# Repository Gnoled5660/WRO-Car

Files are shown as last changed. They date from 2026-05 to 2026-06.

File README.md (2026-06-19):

# WRO-Car

Bildschirmfoto 2026-06-14 um 00 26 38

# Description

This car is meant to be used for a competition called WRO in the category Future-engineers. The goal is to have a car that drives autonomously around obstacles, in lapses ,as fast as possible, without having a collision with the wall or the obstacles. The obstacles may have different colors. Depending on the color, the car has to either drive around it from the left side or from the right side. 

All the 3D CAD models of the car, have been designed entirely from scratch. It is very much possible to design this with much cheaper electronics, but for this competition, we used some higher quality components, as we had a sponsor. 

The car is mainly seperated in two layers. One being the bottom layer, where almost all the non logical electrical components are, and one being the second layer, where all the logical electrical components are.

# Motivation

The main reason why I built this car is because it was required for a robotics competition. This is my first robotics competition, meaning I haven't got that much experience yet, but throughout this project, I have learned a lot about how these electrical components can work together, to be able to move itself. 

# Assembling and Wiring

Assembling it is quite straight forward. All the 3D CAD components have holes, where you can place a heated thread insert inside and screw the parts together. Every component is meant to be screwed or sticked together with glue.

Wiring is also fairly simple. Most of the components have either copper on the pad, so that you can solder the cable on to it or there are pin headers that you can simply connect to it. You just have to be careful with connecting it to the right pins or connecting V+ and Ground correctly. It is also important to use a wire with at least 18 or 20 AWG for the power supply, as it needs to be able to deliver a maximum of 5-6A. The rest of the signal pins can be connected with jumper cables.

The tires are lego tires, as well as the bar that holds the tire. However, it is completely possible to use 3D printed tires. Just be aware, that you might loose some grip.

# CAD Assembly
Starting with the main body, you need to insert heated threat inserts into all of the holes. All the holes are designed for M3 screws.

Bildschirmfoto 2026-06-18 um 15 10 32

Then you can glue the these parts of the steering gear onto the main body. You also have to insert a steel rod from the top to the bottom, to ensure that the component can rotate freely. The steel rods should have a diameter of 3mm.

Bildschirmfoto 2026-06-18 um 15 12 34

Bildschirmfoto 2026-06-18 um 15 15 00

Afterwards, you can add the rest of the components for the steering gear. All the parts that are red in this picture need a steel rod, to ensure flawless rotations.

Bildschirmfoto 2026-06-18 um 15 17 59

Now you can add the rest of the mounts.

Bildschirmfoto 2026-06-18 um 15 20 35

This part is a little bit tricky. It is important, that the servo mounts are added first and then comes the camera mount, because this why it is easier to reach the screws with a screwdriver. 

Bildschirmfoto 2026-06-18 um 15 21 45

The pillars for the second layer also need to be screwed. There is one screw hole on the bottom and two holes for threat inserts on the top. 

Bildschirmfoto 2026-06-18 um 15 23 50

After screwing every component to the mounts, it should look something like this.

Bildschirmfoto 2026-06-18 um 15 25 58

Now for the second layer, the screw sizes may vary from each other, as every component has different sizes of mounting holes. In the cad files you can look up how big the holes of the components are. They are usually 0.2mm bigger than the actual screw.

Bildschirmfoto 2026-06-18 um 15 27 07

If everything is built correctly, the result should look like this one.

Bildschirmfoto 2026-06-18 um 15 29 22

# Usage
The car is meant to be driven autonomously, but withthe raspberry pi5, it is also possible to program it to drive manually. The autonomous car can drive around in lapses and avoid obstacles.

# Firmware
To run the code, you just have to upload the python file on to the raspberry pi 5. Note that you have to setup the pi5 first, including inserting a SD card, as the pi5 usually doesn't come with a SD card. 

Bildschirmfoto 2026-06-14 um 11 54 30

Copy of fallout_zine_template-6

# BOM
|Name |Function |Links |Cost|Quantity|Distributor |
|---|---|---|----|---|---|
|Openmv H7 Plus |Camera |https://www.amazon.de/-/en/OpenMV-Cam-H7-Plus-Genuine-5MP/dp/B09WYQMDX2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|124 |1 |Amazon |
|JGA-370 |Motor |https://smartfactory24.de/en/products/dc-motor-6v-12v-24v-elektrische-getriebe-motor-hohe-ausgerichtet-jga25-370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 |15  |1 |Smartfactory24 |
|Polulu g2 High-power|Motor driver |https://botland.de/dc-motortreiber/5990-g2-high-power-18v17-einkanal-treiber-fur-30v-17a-motoren-pololu-2991-5904422367244.html |36  |1 |Botland |
|Tower Pro MG92B |Servo Steering Joint |https://www.roboter-bausatz.de/p/tower-pro-mg92b-digitaler-mini-servo-mit-metallgetriebe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 |13  |1 |Roboter-Bausatz  |
|Raspberry Pi 5 |Main Processing Unit |https://www.amazon.de/-/en/Raspberry-Pi-SC1111-5-4gb/dp/B0CK3L9WD3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 |90  |1 |Amazon |
|PDB |Power distribution |https://www.premium-modellbau.de/matek-pdb-bis-zu-12s-mit-bec-und-sensor-pdb-hex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 |25  |1 |Premium-Modellbau|
|7.4V Battery |Battery Power supply |https://www.amazon.de/OVONIC-Battery-Aircraft-Helicopter-Specially/dp/B08R726FTY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 |28  |1 |Amazon |
|T-Dean Male Plug |Adapter to connect to Battery|https://www.amazon.de/Premium-Goldstecker-Stecker-verzinnt-Modellbau®/dp/B07C1JSV15/ref=asc_df_B07C1JSV15?mcid=3f313e58521b3b4d985251ab4e02ac79&th=1&tag=googshopde-21&linkCode=df0&hvadid=725809613218&hvpos=&hvnetw=g&hvrand=17068902777536047627&hvpone=&hvptwo=&hvqmt=&hvdev=c&hvdvcmdl=&hvlocint=&hvlocphy=9044393&hvtargid=pla-2399552437568&hvocijid=17068902777536047627-B07C1JSV15-&hvexpln=0 |4 |1 |Amazon |
|LTC3780 |Step down converter for motor|https://www.roboter-bausatz.de/p/spannungswandler-step-up-down-10a-dc-5v-32v-auf-1v-30v-ltc3780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 |18  |1 |Roboter-Bausatz  |
|D36V50F5 |Step down converter for pi5  |https://botland.de/abwartswandler/16392-d36v50f5-5v-8a-abwartswandler-pololu-4091-5904422372125.html |29  |1 |Botland |
|MicroSD |For the pi5 |https://www.voelkner.de/index.php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 |11  |1 |voelkner |
|Filament | 189g | |5 | | |
|total | | | 398| | |

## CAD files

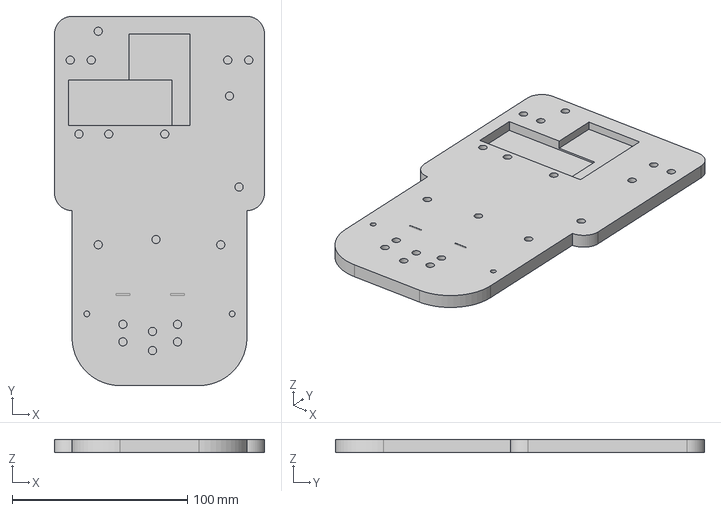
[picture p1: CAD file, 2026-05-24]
CAD/main body.step
120.0 x 211.0 x 7.50 mm

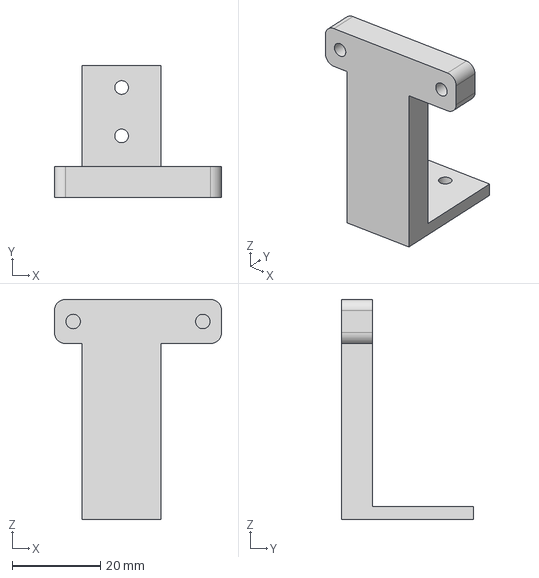
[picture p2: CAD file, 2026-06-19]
CAD/Camera holder.step
38.0 x 30.0 x 50.0 mm

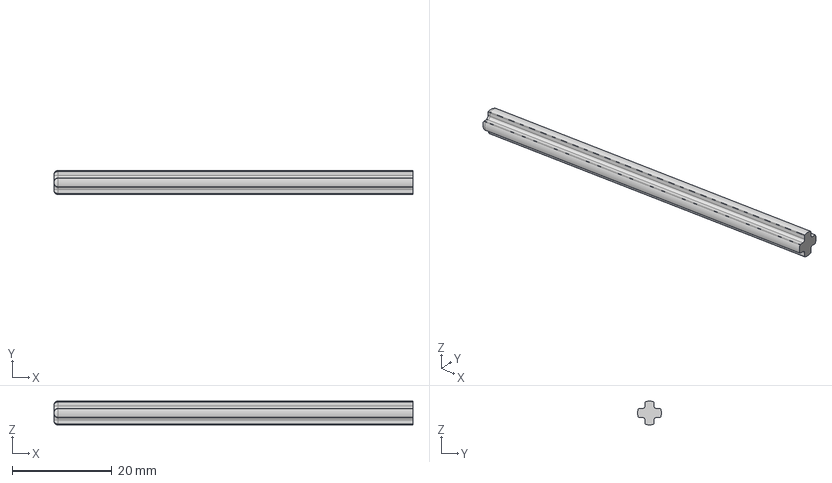
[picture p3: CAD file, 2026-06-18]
CAD/3708 Black Technic Axle 12 v1.step
72.0 x 4.80 x 4.80 mm

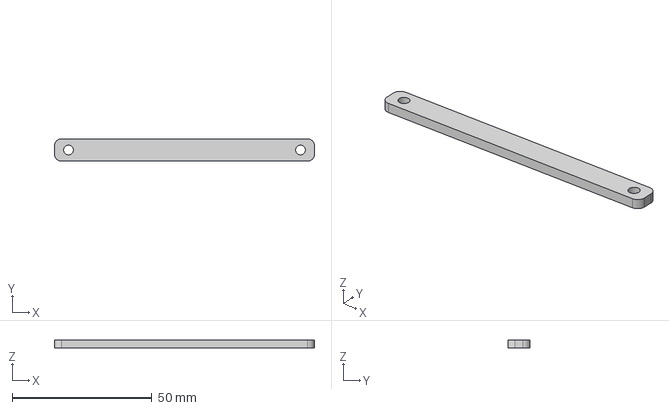
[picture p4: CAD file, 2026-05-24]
CAD/Steering Right 2.step
93.0 x 8.00 x 3.00 mm

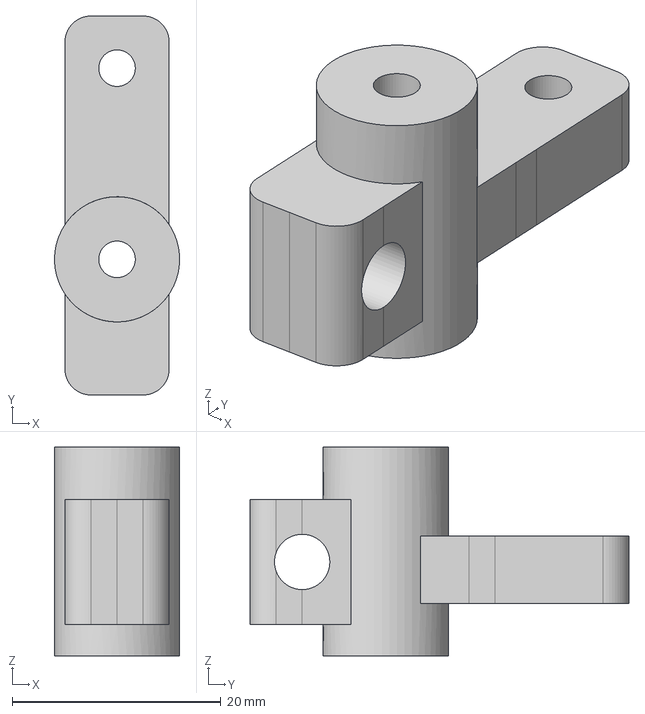
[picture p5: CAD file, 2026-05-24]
CAD/Steering Right 1.step
12.0 x 36.3 x 20.0 mm

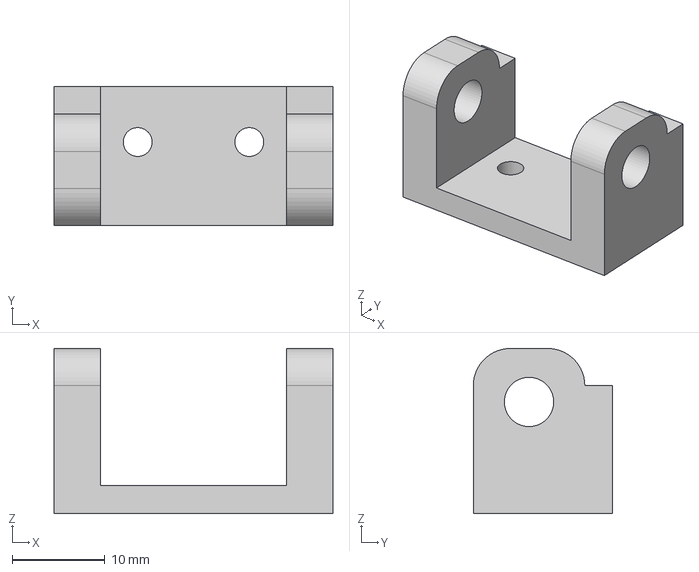
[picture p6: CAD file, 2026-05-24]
CAD/Motor wheel holder 2.step
30.0 x 15.0 x 17.8 mm

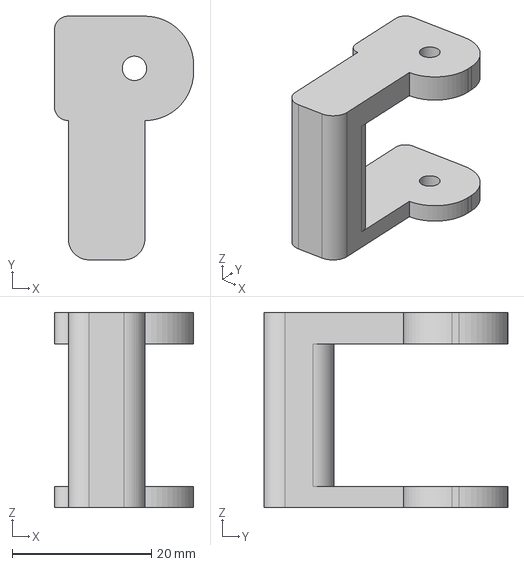
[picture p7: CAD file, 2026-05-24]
CAD/Steering Left 3.step
20.0 x 35.0 x 28.0 mm

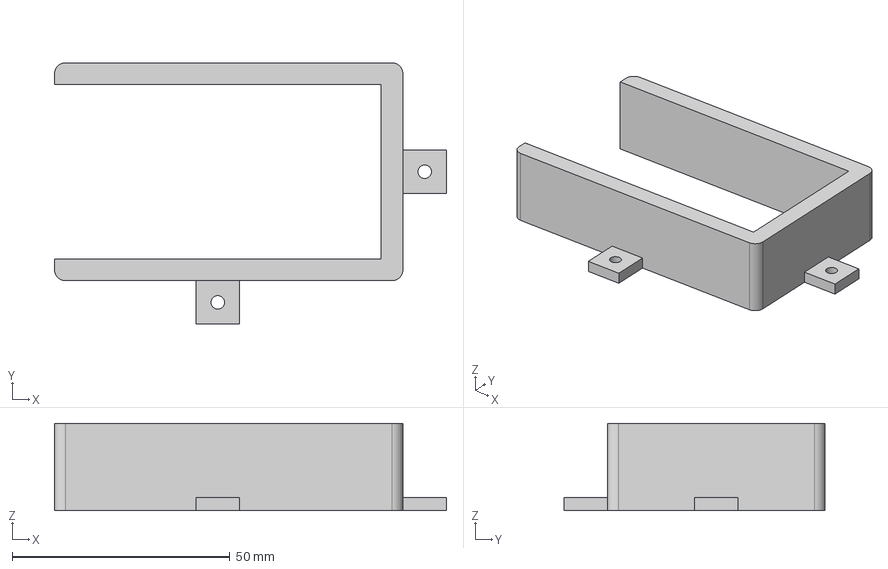
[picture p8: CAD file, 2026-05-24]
CAD/Battery Holder.step
90.0 x 60.0 x 20.0 mm

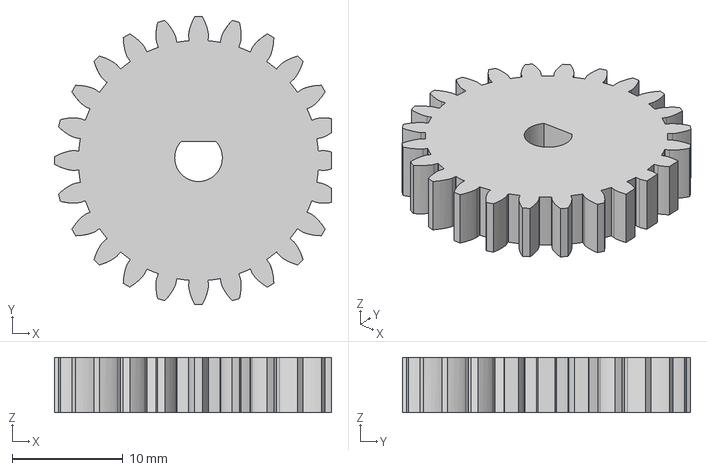
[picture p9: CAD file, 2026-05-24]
CAD/Spur Gear 24 teeth.step
25.0 x 26.0 x 5.00 mm

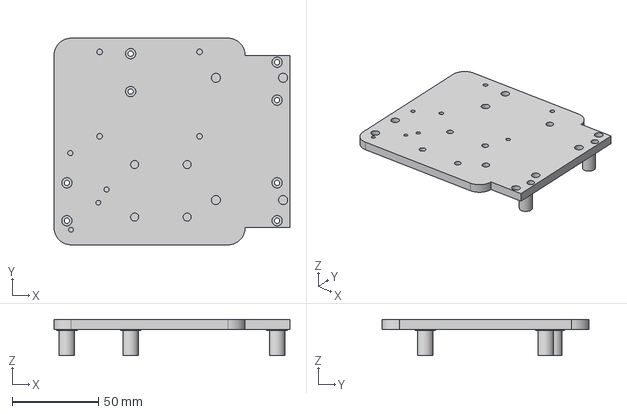
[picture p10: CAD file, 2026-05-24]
CAD/Second Layer.step
137.0 x 120.0 x 21.0 mm

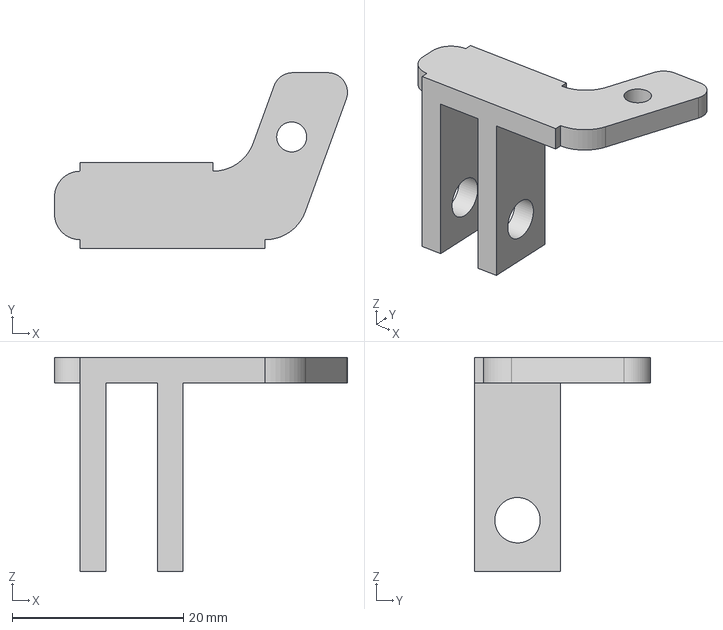
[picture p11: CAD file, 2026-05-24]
CAD/Steering Right 4.step
34.2 x 20.5 x 25.0 mm

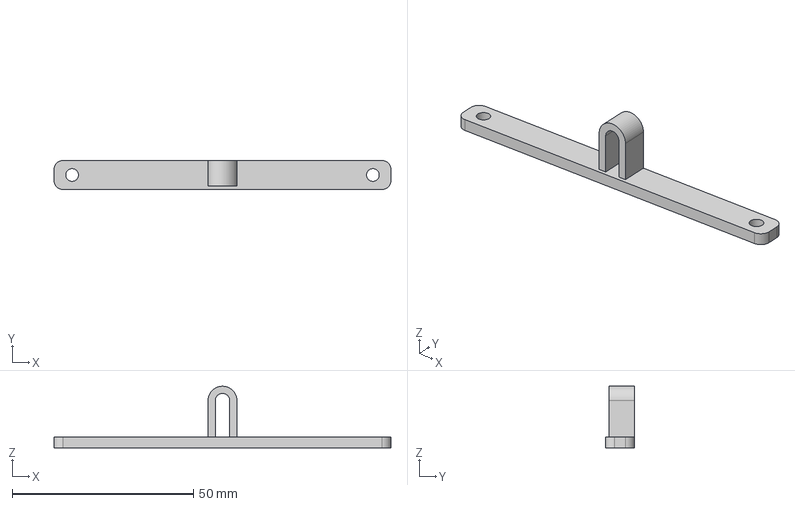
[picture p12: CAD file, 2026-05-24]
CAD/Steering Left 2.step
93.0 x 8.00 x 17.0 mm

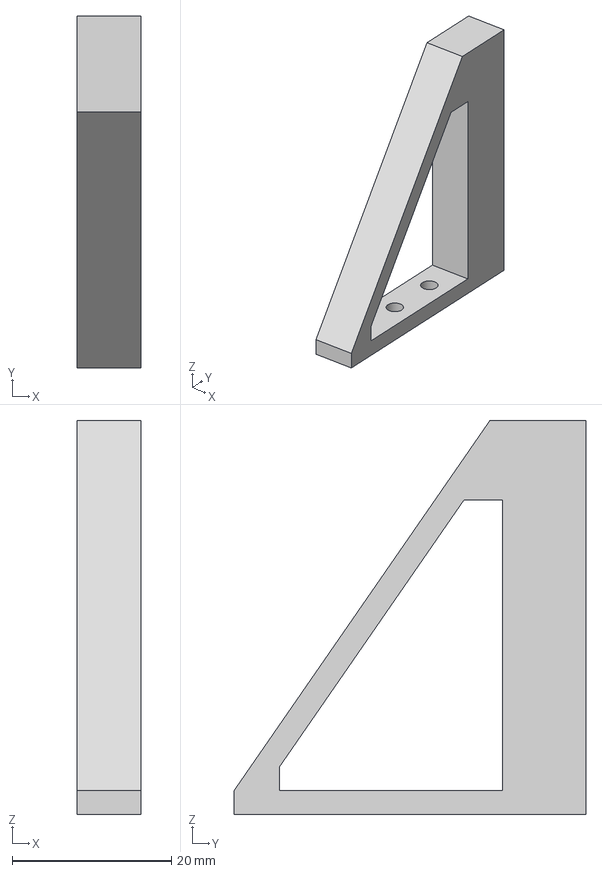
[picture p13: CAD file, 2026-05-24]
CAD/Servo Holder 1.step
8.00 x 44.2 x 49.5 mm

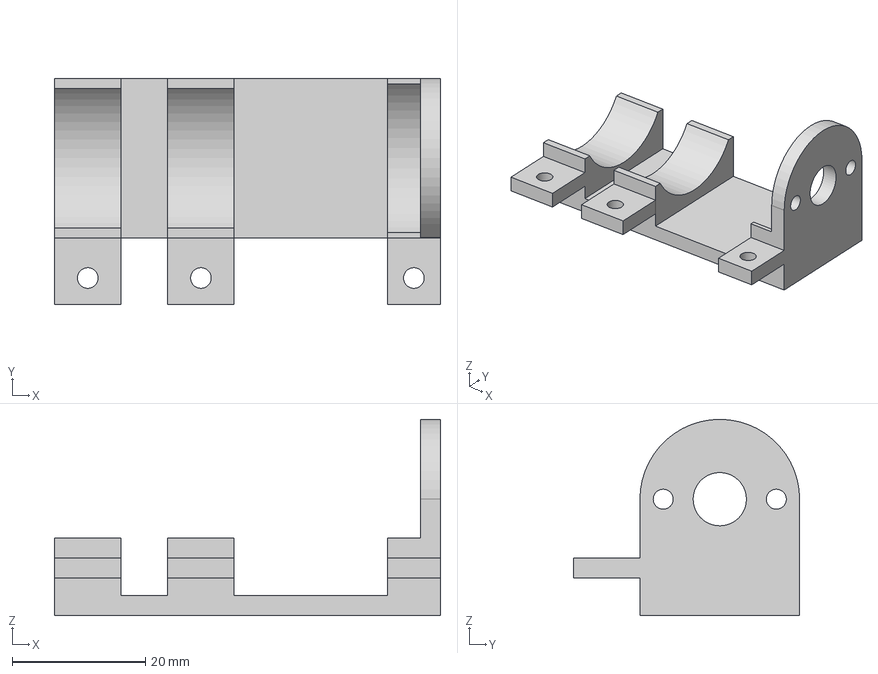
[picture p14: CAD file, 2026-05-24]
CAD/Motor Mount.step
58.0 x 34.0 x 29.5 mm

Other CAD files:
CAD/Steering Left 1.step
CAD/Motor wheel holder 1.step
CAD/Steering Right 3.step
CAD/Servo Holder 2.step
CAD/50450 White Technic Axle 32 v1.step
CAD/Steering Left 4.step

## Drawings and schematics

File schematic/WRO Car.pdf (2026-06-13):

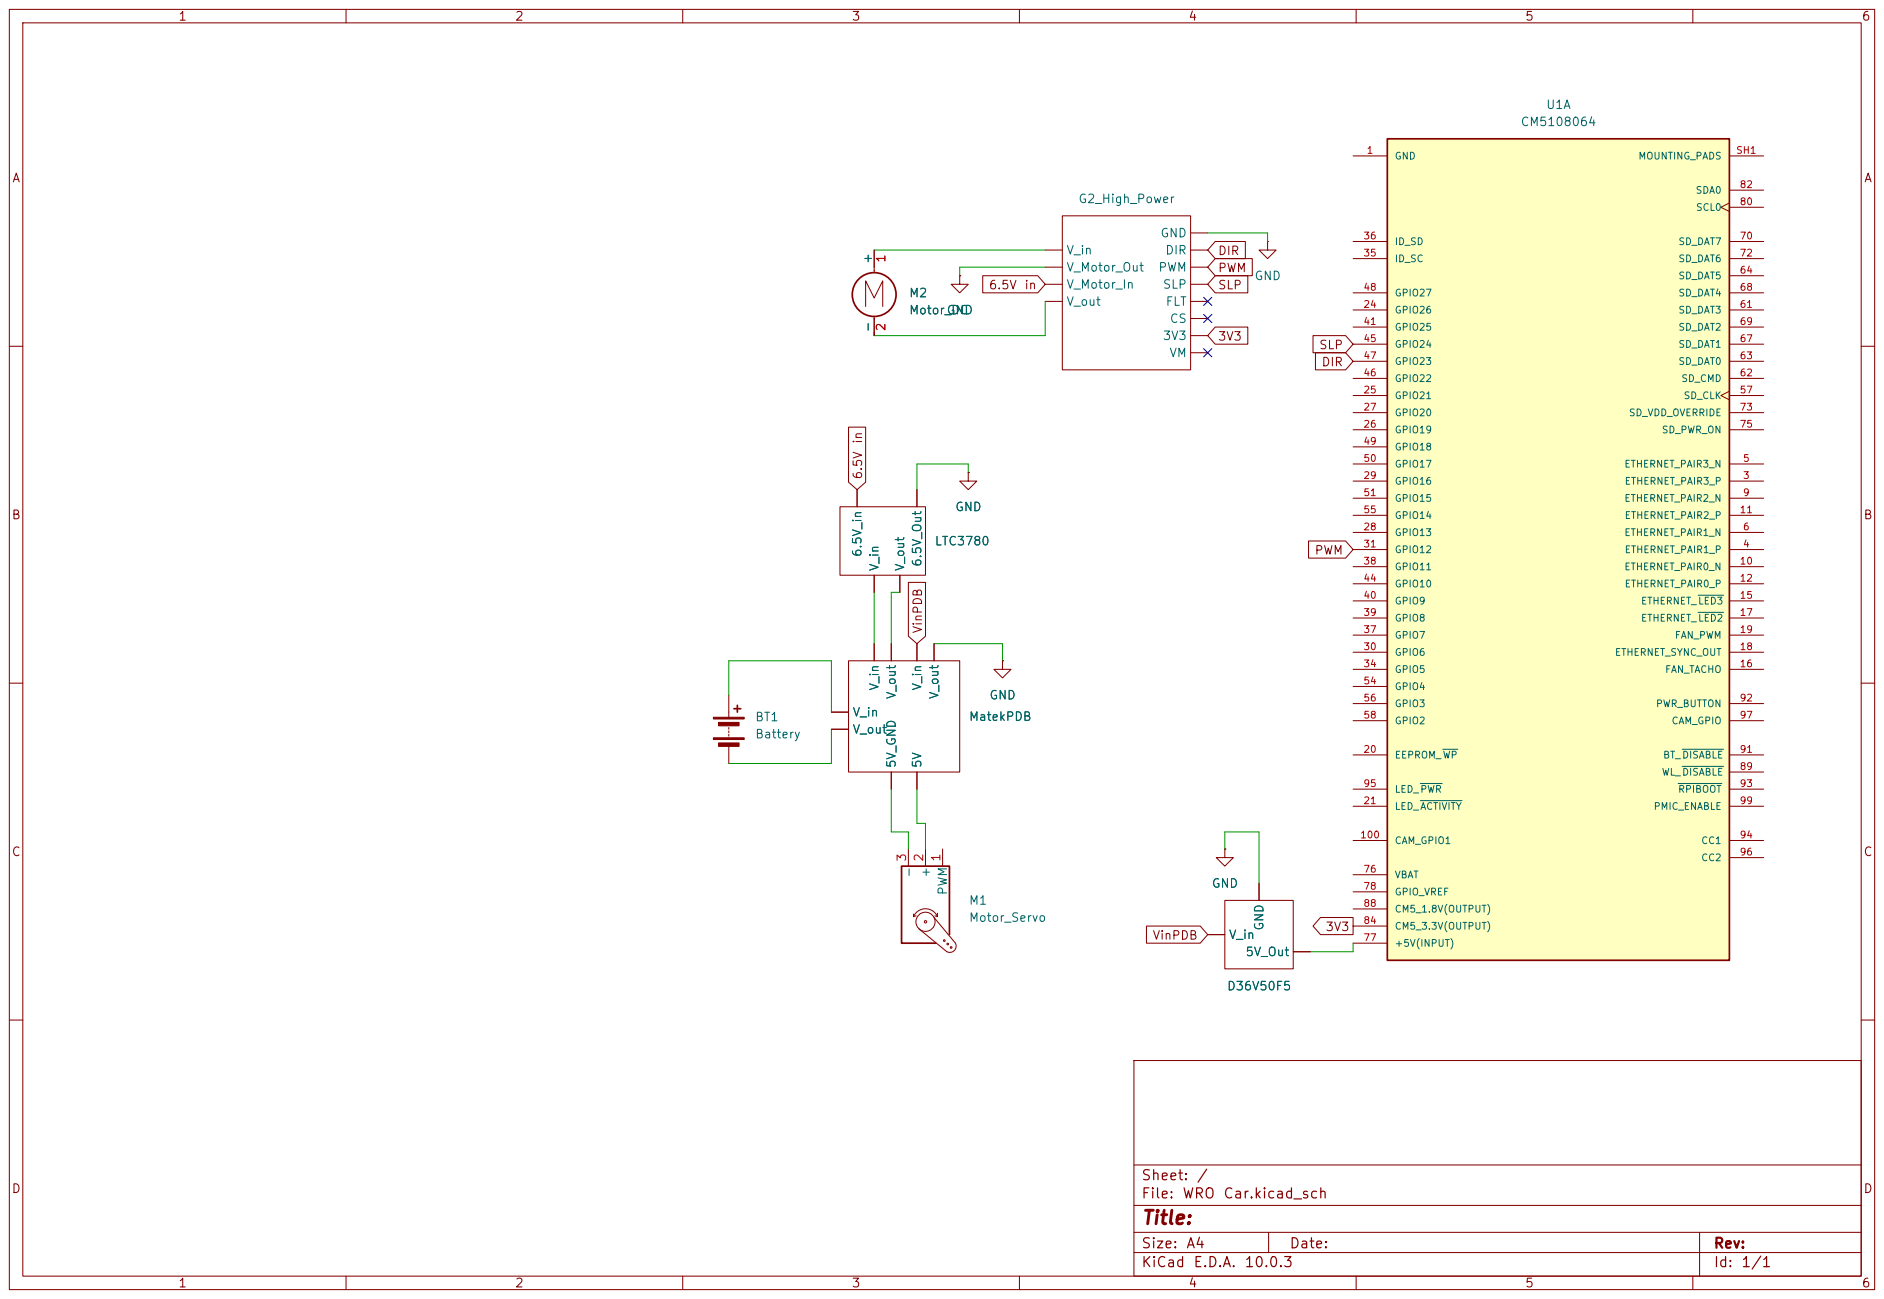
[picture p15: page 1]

Size: A4 | Rev:
KiCad E.D.A. 10.0.3 | Id: 1/1

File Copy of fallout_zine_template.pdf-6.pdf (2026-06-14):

# Robo Car

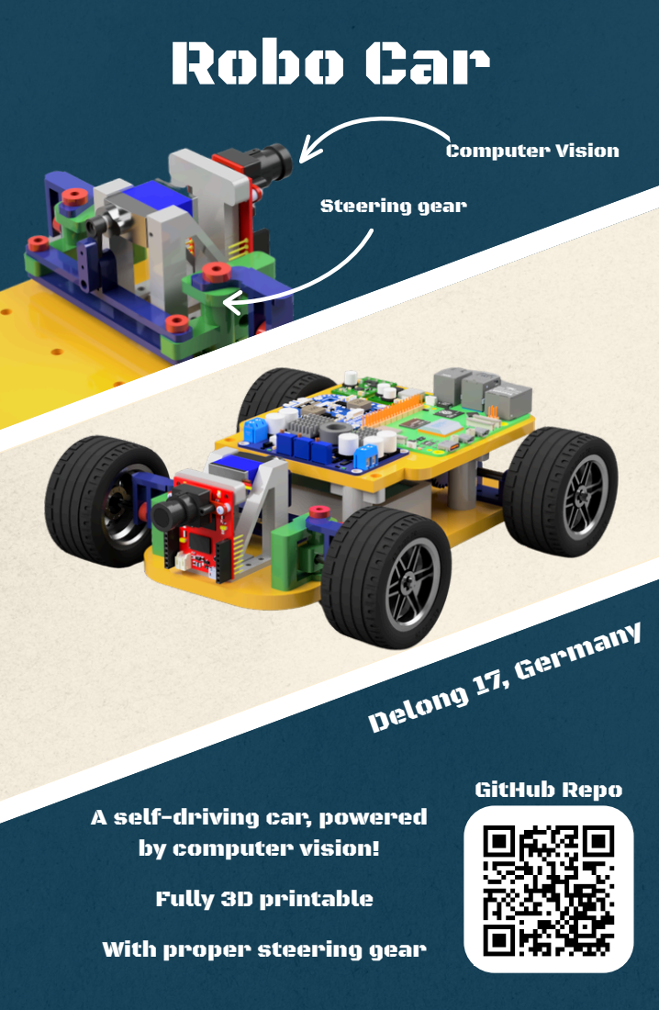
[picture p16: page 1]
Delong 17, Germany; GitHub Repo; Computer Vision; Steering gear

A self-driving car, powered
by computer vision!
Fully 3D printable
With proper steering gear

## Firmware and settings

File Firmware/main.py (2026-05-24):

import time
import struct
import cv2
import numpy as np
import serial
from rpi_hardware_pwm import HardwarePWM
from gpiozero import PWMOutputDevice, DigitalOutputDevice

OPENMV_PORT, OPENMV_BAUD = "/dev/ttyACM0", 115200
PWM_CHIP, PWM_CHANNEL, PWM_FREQ_HZ = 0, 2, 50
PULSE_CENTER = 1600
MOTOR_PWM_PIN, MOTOR_DIR_PIN, MOTOR_SLP_PIN = 12, 23, 24
MOTOR_SPEED = 0.40
MIN_PX = 350   

def lab_to_cv(t):
    Lmin, Lmax, Amin, Amax, Bmin, Bmax = t
    lo = np.array([int(Lmin * 2.55), Amin + 128, Bmin + 128], dtype=np.uint8)
    hi = np.array([int(Lmax * 2.55), Amax + 128, Bmax + 128], dtype=np.uint8)
    return lo, hi

THRESH_RED   = lab_to_cv((45, 55,  20,  38,   0, 20))
THRESH_GREEN = lab_to_cv((30, 42, -32, -18,   5, 20))

ser = serial.Serial(OPENMV_PORT, OPENMV_BAUD, timeout=2)
time.sleep(0.5)
ser.reset_input_buffer()

servo = HardwarePWM(pwm_channel=PWM_CHANNEL, hz=PWM_FREQ_HZ, chip=PWM_CHIP)
servo.start((PULSE_CENTER / 20000) * 100)  

motor_pwm = PWMOutputDevice(MOTOR_PWM_PIN, frequency=1000, initial_value=0)
motor_dir = DigitalOutputDevice(MOTOR_DIR_PIN, initial_value=False)
motor_slp = DigitalOutputDevice(MOTOR_SLP_PIN, initial_value=True)   # aufwecken
time.sleep(0.1)


def grab_frame():
    ser.write(b"snap")
    length_bytes = ser.read(4)
    if len(length_bytes) != 4:
        return None
    length = struct.unpack("<L", length_bytes)[0]
    if length == 0 or length > 200_000:
        ser.reset_input_buffer()
        return None
    jpeg = ser.read(length)
    if len(jpeg) != length:
        return None
    return cv2.imdecode(np.frombuffer(jpeg, np.uint8), cv2.IMREAD_COLOR)


def has_color(lab_img, thresh):
    mask = cv2.inRange(lab_img, thresh[0], thresh[1])
    return int(cv2.countNonZero(mask)) >= MIN_PX


def forward():
    motor_dir.off()
    motor_pwm.value = MOTOR_SPEED


def backward():
    motor_dir.on()
    motor_pwm.value = MOTOR_SPEED


def stop():
    motor_pwm.value = 0
  
try:
    while True:
        frame = grab_frame()
        if frame is None:
            time.sleep(0.05)
            continue

        lab = cv2.cvtColor(frame, cv2.COLOR_BGR2LAB)
        green = has_color(lab, THRESH_GREEN)
        red   = has_color(lab, THRESH_RED)

        if green:
            forward()
        elif red:
            backward()
        else:
            stop()
            print("--    -> STOP")

        time.sleep(0.05)

except KeyboardInterrupt:
    print("Cancel")

finally:
    motor_pwm.value = 0
    motor_slp.off()
    servo.change_duty_cycle((PULSE_CENTER / 20000) * 100)
    time.sleep(0.2)
    servo.stop()
    ser.close()

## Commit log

2026-05-24 Create schematic
2026-05-24 Update BOM.csv format and content
    [BOM.csv]
2026-05-24 Implement motor control based on color detection
2026-05-26 Update BOM.csv to correct header and links
    [BOM.csv]
2026-05-26 Rename BOM-2 - BOM-2.csv.csv to BOM.csv
    [BOM.csv]
2026-06-13 Update CAD source file
2026-06-18 Update README with assembly instructions clarification
    Removed duplicate instructions for gluing steering gear parts and added clarification on inserting steel rods.
2026-06-19 Rename Kamerahalterung.step to Camera holder.step
    [Camera holder.step]
